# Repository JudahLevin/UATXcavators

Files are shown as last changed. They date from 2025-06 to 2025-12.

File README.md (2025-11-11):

# Purpose of this repo
Facilitate UATXcavators technical subTeam comms with a Notification System that is Automated (NSA): changes are made known to *all relevant subTeam members* with no manual effort.

# What this repo does
- Logs commits from live edits of the UATXcavators' technical Google Sheets in "logs" folder
- Acts as the primary location for making commits to UATXcavators' technical docs
- Broadcasts commits to the UATXcavators Discord to be interpreted by relevant subTeam members

---
Relevant doc/sheet links: 

## [UATXcavators Part Specs](https://docs.google.com/spreadsheets/d/1raRMg_BoY4irnRXD5xzt5HqwL2nL2Hntu02hM1NV3XU/edit?usp=sharing)
## [Industrial Automation Specs](https://docs.google.com/document/d/1iF8lcYDWoOoWy3NKHDPTQ_0LZirL0NmDES7pJT3RLTE/edit?usp=sharing)
## [How to control the prototype actuator](https://docs.google.com/document/d/1RFi-qUUx1wFrG9wh1VayHfOVhKBDCqDUs143Y6IG7fw/edit?usp=sharing)

🚨 To reiterate 🚨:
- All technical spreadsheet changes are made in linked Google Sheets.
- All technical document changes are made in this UATXcavators repo or linked Google Docs.

To join our Discord for subTeam comms and the AI summary system, [click this link.](https://discord.gg/Ns4jA3gE)

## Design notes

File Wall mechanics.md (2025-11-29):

## Stress from Torque on Segment / Push Plate / L-Bracket Bolts

**Given:**

- $$n = 4$$  
- Worst-case torque per rib: $$T = 1000\ \text{Nm}$$  
- Minimum bolt radius: $$r = 0.225\ \text{m}$$  
- Net bolt force:  
  $$F_{\text{bolt}} = \frac{T}{r} = 4444.4\ \text{N}$$

**Bolt Shear Check**

- Allowable shear for metric Grade 8:  
  $$\tau_{\text{allow}} = 0.3\,\sigma_y = 249\ \text{MPa}$$
- Required bolt shear area:  
  $$A_{\text{req}} = \frac{F_{\text{bolt}}}{\tau_{\text{allow}}} = 0.00001716\ \text{m}^2$$
- Actual tensile stress area (1/2"-28 Grade 8 hex bolt):  
  $$A = 0.0001096772\ \text{m}^2 \gg A_{\text{req}}$$

---

## Bearing on the 3/8" Plate Around the Bolt Hole

- Allowable bearing stress (SF = 4):  
  $$p_{\text{allow}} = \frac{\sigma_y}{4} = 62.5\ \text{MPa}$$
- Bolt diameter: $$d = 0.0127\ \text{m}$$  
- Plate thickness: $$t = 0.009525\ \text{m}$$  
- Bearing stress:  
  $$p = \frac{F_{\text{bolt}}}{d\,t} = 36.7\ \text{MPa} < p_{\text{allow}}$$

We do not worry about bracket rotation because four L-brackets are equally spaced around the segment and balanced for torque.

---

## Segment / Push Plate Rib L-Bracket — Axial Check

- $$n = 4$$  
- Hole diameter: $$d = 0.0127\ \text{m}$$  
- Width: $$b = 0.0381\ \text{m}$$  
- L-bracket thickness: $$t_l = 0.01905\ \text{m}$$  
- Plate thickness: $$t_p = 0.0095\ \text{m}$$  
- Applied force on upright leg: $$F = 8896\ \text{N}$$

### Section Properties

- Second moment of area:  
  $$I = \frac{b\,t_l^3}{12} = 2.2\times 10^{-8}\ \text{m}^4$$
- Neutral-axis extreme fiber:  
  $$c = \frac{b}{2} = 0.01905\ \text{m}$$
- Load height:  
  $$h_v = 0.01905\ \text{m}$$

### Allowable Deflection

- $$\delta_{\text{allow}} = \frac{h_v}{300} = 0.0000635\ \text{m}$$

### Bending Stress at the Heel

- $$\sigma_b = \frac{6Fh_v}{b\,t_l^2} = 73.5\ \text{MPa}$$  
  (within allowable, ~4× FOS)

### Shear Stress at the Heel

- $$\tau = \frac{F}{b\,t_l} = 12.3\ \text{MPa}$$  
  (well within allowable)

### Bearing Stress on Plate at Bolt Hole

- $$\sigma_{\text{bearing}} = \frac{F_{\text{bolt}}}{t_p\,d} = 73.7\ \text{MPa}$$  
  (within allowable)

### Bracket Deflection

- $$\delta = \frac{F\,h_v^3}{3EI} = 0.00000466\ \text{m}$$  
  (far below $$\delta_{\text{allow}}$$)

---

# TBM Wall Axial Stress

**Given:**

- Axial compression: $$N = 35585\ \text{N}$$
- Wall/rib length: $$L = 0.508\ \text{m}$$
- Bending moment (worst case): $$M = 18077\ \text{Nm}$$
- Allowable combined stress (4× FOS):  
  $$\sigma_{\text{allow}} = \frac{\sigma_y}{4} = 60\ \text{MPa}$$
- Rib radius: $$R = 0.27\ \text{m}$$
- Number of ribs: $$n = 4$$
- Rib area: $$A = \text{unknown (solve for required)}$$  
- Skin: 12-gauge sheet (≈2.7 mm) forming thin cylinder

### Axial Stress

Treat ribs as $$n$$ point-areas around radius $$R$$:

- Axial stress:  
  $$\sigma_N = \frac{N}{nA}$$

### Bending Stress from Wall Moment

Section inertia (ribs dominate):

- $$I = n A R^2$$

Bending stress:

- $$\sigma_b = \frac{M R}{I} = \frac{M}{n A R}$$

### Combined Stress

- $$\sigma_c = \sigma_N + \sigma_b$$
- $$\sigma_c = \frac{N}{nA} + \frac{M}{nAR} = \frac{N + \frac{M}{R}}{nA}$$

Set equal to allowable:

- $$A \ge \frac{N + M/R}{n\,\sigma_{\text{allow}}}$$

Numerically:

- $$A \ge \frac{35585 + 18077/0.27}{4 \cdot 60\times 10^6} = 0.000427\ \text{m}^2$$

This corresponds to a rib cross-section of:

- $$21\ \text{mm} \times 21\ \text{mm}$$  
meeting minimum stress requirements.

---

# TBM Wall Rib Buckling Check

- Rib load (per rib): $$P_{\text{rib}} = 8896\ \text{N}$$
- Young’s modulus: $$E = 200\ \text{GPa}$$
- Effective length factor (pinned–pinned): $$K = 1$$
- Rib height/length: $$L = 0.508\ \text{m}$$
- Rib width = $$b$$, thickness = $$t$$

### Euler Buckling Load

For a rectangular rib:

- $$P_{\text{cr}} = \frac{\pi^2 E\, t\, b^3}{12 (K L)^2}$$

With 4× FOS:

- $$P_{\text{cr}} = 35585\ \text{N}$$

Solve for minimum stiffness product:

- $$t b^3 \ge \frac{P_{\text{cr}} \cdot 12 (K L)^2}{\pi^2 E} = 5.6\times 10^{-8}$$

### Example Rib Size (Radially Oriented for Strong Axis)

Let:

- $$b = 38.1\ \text{mm} = 0.0381\ \text{m} \ \text{(1.5 in)}$$  
- $$t = 38.1\ \text{mm} = 0.0381\ \text{m} \ \text{(1.5 in)}$$

Then:

- $$t b^3 = 0.0381^4 = 2.11\times 10^{-6} \gg 5.6\times 10^{-8}$$
- Cross-section area:  
  $$b t = .00145\ \text{m}^2 \gg 0.000427\ \text{m}^2$$

**Conclusion:**  
A 38.1 mm × 38.1 mm (1.5 in × 1.5 in) rib vastly exceeds both bending-compression and Euler-buckling requirements, even under 4× safety factor.

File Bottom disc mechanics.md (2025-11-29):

# Cantilever-Strip and Stiffened-Strip Model for Ring Plate Under Column Loads

## 1. Setup and Problem Description

We have a **flat annular plate (ring)**:

* Inner diameter (ID) is **fixed** (built-in support).
* Outer diameter (OD) is **free**, except at **four square columns** welded/bolted along the outer edge.
* Each column is loaded in **downward axial force** (in side view), so the plate is loaded in **out-of-plane bending**.
* The ID reacts these loads by providing a fixed (clamped) support around the inner circumference.

Rather than analyzing the entire ring at once, we look at **one representative strip** of plate **under a column**, and model how that strip bends out of plane between:

* The **ID clamp** (fixed end), and
* The **column footprint at the OD** (loaded end).

The goal is:

1. Show that a **bare plate** is overstressed under the column load.
2. Develop a **composite plate + stiffener model** to reduce bending stress to acceptable levels.

---

## 2. Justification for the Cantilever-Strip Model

Because:

* The column load is localized under each column footprint, and
* The ID is effectively a continuous fixed support,

it is reasonable to idealize:

* A **radial strip** of the plate, of effective width $$b$$, under a given column.
* That strip behaves approximately like a **cantilever beam**:

  * Fixed at the ID (built-in),
  * Span length $$L$$ (radial distance from ID to column),
  * Tip load $$F$$ (column load per strip).

This ignores 2D plate effects and circumferential load spreading, but it is **conservative** for checking local bending under a column because:

* Bending is highest near the fixed end.
* The strip model directly captures the dominant bending mechanism: **radial plate bending between OD and ID**.

So we treat the plate strip as a **rectangular-section cantilever beam** with:

* Beam depth (bending direction): plate thickness $$t$$
* Beam width (into page): effective width $$b$$

---

## 3. Un-Stiffened Plate: Bending Stress Check

For a **bare plate strip** (no rib):

* Cantilever span:
  $$L = 0.17911976\ \text{m}$$
* Plate thickness:
  $$t = 0.0127\ \text{m}$$
* Effective strip width:
  $$b = 0.05\ \text{m}$$
* Tip load (per strip):
  $$F = 8896.4\ \text{N}$$

### 3.1. Bending moment at the fixed end

For a tip-loaded cantilever:

$$
M_{\max} = F L
= 8896.4 \cdot 0.17911976
\approx 1593.5\ \text{N·m}
$$

### 3.2. Section properties of the plate strip

Rectangular cross-section (width $$b$$, thickness $$t$$):

* Second moment of area:

$$
I = \frac{b t^3}{12}
\approx 8.53 \times 10^{-9}\ \text{m}^4
$$

* Distance to extreme fiber (top/bottom):

$$
c = \frac{t}{2} = 0.00635\ \text{m}
$$

### 3.3. Maximum bending stress

$$
\sigma_{\max}
= \frac{M_{\max} c}{I}
= \frac{1593.5 \cdot 0.00635}{8.53 \times 10^{-9}}
\approx 1.19 \times 10^{9}\ \text{Pa}
= 1186\ \text{MPa}
$$

This is **far above** the yield strength of typical structural steels (e.g. 250–500 MPa).
Conclusion: **a 12.7 mm plate alone is nowhere near sufficient** for this load and span, and requires stiffening.

---

## 4. Composite Plate + Stiffener Model (New Coordinate System)

To reduce bending stress, we weld a **longitudinal stiffening rib** under the plate strip, along the entire span. The plate + stiffener form a **T-shaped composite section**.

We use the following **right-hand 3D coordinate system**:

* **Y**: vertical **height** direction (bending direction)
* **Z**: along the **cantilever length** (span), from fixed end to loaded end
* **X**: through-plate **thickness** direction

We analyze the T-section in the **Y–Z plane**, with bending about the **X-axis**.

### 4.1. Geometry and variables

* Plate (flange):

  * Thickness in X:
    $$t\ (\text{m})$$
  * Effective strip width (circumferential):
    $$b\ (\text{m})$$

* Stiffener (web):

  * Height in Y (from plate underside down):
    $$h\ (\text{m})$$
  * Thickness in X:
    $$t_s\ (\text{m})$$

* Cantilever span in Z:
  $$L\ (\text{m})$$

* Tip load at $$Z = L$$:
  $$F\ (\text{N})$$

### 4.2. Coordinate convention in Y

Let:

* $$Y = 0$$: **bottom of the stiffener**
* $$Y = h$$: **plate–stiffener interface**
* $$Y = h + t$$: **top of the plate**

### 4.3. Component areas

$$
A_p = b t
$$

$$
A_s = h t_s
$$

$$
A = A_p + A_s
$$

### 4.4. Component centroids (in Y)

$$
Y_p = h + \frac{t}{2}
$$

$$
Y_s = \frac{h}{2}
$$

### 4.5. Neutral axis location $$\bar{Y}$$ (from bottom of stiffener)

$$
\bar{Y}
= \frac{A_p Y_p + A_s Y_s}{A_p + A_s}
= \frac{b t \left(h + \frac{t}{2}\right) + h t_s \left(\frac{h}{2}\right)}
{b t + h t_s}
$$

### 4.6. Second moment of area about the neutral axis

Plate local inertia:

$$
I_{p0} = \frac{b t^3}{12}
$$

Shifted:

$$
I_p = I_{p0} + A_p (Y_p - \bar{Y})^2
$$

Stiffener local inertia:

$$
I_{s0} = \frac{t_s h^3}{12}
$$

Shifted:

$$
I_s = I_{s0} + A_s (\bar{Y} - Y_s)^2
$$

Total:

$$
I = I_p + I_s
$$

### 4.7. Extreme fiber distances

Top:

$$
Y_{\text{top}} = h + t
$$

$$
c_{\text{top}} = (h + t) - \bar{Y}
$$

Bottom:

$$
c_{\text{bot}} = \bar{Y}
$$

Largest:

$$
c_{\max} = \max(c_{\text{top}},\ c_{\text{bot}})
$$

### 4.8. Bending moment and maximum stress

$$
M_{\max} = F L
$$

Stress at distance $$c$$:

$$
\sigma = \frac{M_{\max} c}{I}
$$

Maximum:

$$
\sigma_{\max}
= \frac{F L , c_{\max}}{I}
= \frac{F L , \max\left((h + t) - \bar{Y},\ \bar{Y}\right)}
{I_p + I_s}
$$

with:

$$
I_p = \frac{b t^3}{12} + b t (Y_p - \bar{Y})^2
$$

$$
I_s = \frac{t_s h^3}{12} + h t_s (\bar{Y} - Y_s)^2
$$

and:

$$
Y_p = h + \frac{t}{2}, \quad
Y_s = \frac{h}{2}, \quad
\bar{Y}
= \frac{b t \left(h + \frac{t}{2}\right) + h t_s \left(\frac{h}{2}\right)}
{b t + h t_s}
$$

This model gives us a **closed-form way to size the stiffener** ($$h, t_s$$) and effective strip width $$b$$ for a given load $$F$$, span $$L$$, and plate thickness $$t$$ to ensure:

$$
\sigma_{\max} \leq \sigma_{\text{allowable}}
$$

for the chosen material and safety factor.

---

## 5. Numerical Example: Stiffened-Strip Bending Stress Calculation

This section applies the composite stiffened-strip model to a representative geometry. A plate strip of width $$b$$ is reinforced by a vertical stiffener of height $$h$$ and thickness $$t_s$$, forming a T-shaped composite section. The strip behaves as a cantilever of span $$L$$ carrying a tip load $$F$$.

### 5.1. Input Geometry and Loading

* Plate thickness:
  $$t = 0.009525\ \text{m}$$
* Plate strip width:
  $$b = 0.05\ \text{m}$$
* Stiffener height:
  $$h = 0.075\ \text{m}$$
* Stiffener thickness:
  $$t_s = 0.025\ \text{m}$$
* Tip load:
  $$F = 8896.4\ \text{N}$$
* Cantilever span:
  $$L = 0.17911976\ \text{m}$$

The coordinate system uses:

* $$Y$$: vertical direction (plate + stiffener height)
* $$Z$$: cantilever length
* $$X$$: plate/stiffener thickness direction

---

### 5.2. Cross-Sectional Properties

Plate area:

$$
A_p = b t = 4.7625\times 10^{-4}\ \text{m}^2
$$

Stiffener area:

$$
A_s = t_s h = 1.875\times 10^{-3}\ \text{m}^2
$$

Plate centroid:

$$
Y_p = h + \frac{t}{2} = 0.0797625\ \text{m}
$$

Stiffener centroid:

$$
Y_s = \frac{h}{2} = 0.0375\ \text{m}
$$

Composite neutral axis (from bottom of stiffener):

$$
\bar{Y}
= \frac{A_p Y_p + A_s Y_s}{A_p + A_s}
\approx 0.0461\ \text{m}
$$

---

### 5.3. Second Moment of Area

Plate about its own centroid:

$$
I_{p0} = \frac{b t^3}{12} \approx 3.60\times 10^{-9}\ \text{m}^4
$$

Shifted to global NA:

$$
I_p = I_{p0} + A_p (Y_p - \bar{Y})^2
\approx 5.45\times 10^{-7}\ \text{m}^4
$$

Stiffener about its own centroid:

$$
I_{s0} = \frac{t_s h^3}{12} \approx 8.79\times 10^{-7}\ \text{m}^4
$$

Shifted to global NA:

$$
I_s = I_{s0} + A_s (\bar{Y} - Y_s)^2
\approx 1.02\times 10^{-6}\ \text{m}^4
$$

Total composite inertia:

$$
I = I_p + I_s \approx 1.56\times 10^{-6}\ \text{m}^4
$$

---

### 5.4. Extreme-Fiber Distances

Top of plate at $$Y = h + t = 0.084525\ \text{m}$$:

$$
c_{\text{top}} = (h+t) - \bar{Y} \approx 0.0385\ \text{m}
$$

Bottom of stiffener at $$Y = 0$$:

$$
c_{\text{bot}} = \bar{Y} \approx 0.0461\ \text{m}
$$

Maximum distance:

$$
c_{\max} = c_{\text{bot}}
$$

---

### 5.5. Bending Moment and Stress

Maximum bending moment at the fixed end:

$$
M_{\max} = F L
= 8896.4 \cdot 0.17911976
\approx 1593.5\ \text{N·m}
$$

Top fiber stress:

$$
\sigma_{\text{top}} = \frac{M_{\max} c_{\text{top}}}{I}
\approx 3.93 \times 10^{7}\ \text{Pa}
= 39.3\ \text{MPa}
$$

Bottom fiber stress:

$$
\sigma_{\text{bot}} = \frac{M_{\max} c_{\text{bot}}}{I}
\approx 4.70 \times 10^{7}\ \text{Pa}
= 47.0\ \text{MPa}
$$

Maximum bending stress:

$$
\boxed{\sigma_{\max} \approx 47\ \text{MPa}}
$$

---

### 5.6. Interpretation

Even with a relatively thin plate ($$t=9.5\ \text{mm}$$), the stiffener of height $$h=75\ \text{mm}$$ and thickness $$t_s=25\ \text{mm}$$ dramatically increases the bending rigidity. Under the applied load of $$F=8896.4\ \text{N}$$ at a span of $$L=0.17911976\ \text{m}$$, the resulting bending stress is:

* $$\sigma_{\max} \approx 47\ \text{MPa}$$, giving
* $$\text{SF} \approx \dfrac{250}{47} \approx 5.3$$ against $$250\ \text{MPa}$$ steel, or
* $$\text{SF} \approx \dfrac{350}{47} \approx 7.5$$ against $$350\ \text{MPa}$$ steel.

This confirms the stiffened-strip approach provides a structurally sound load path for the ring plate under column loads for the updated shorter cantilever span.

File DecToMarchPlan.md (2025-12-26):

# UATXcavators Plans December - March

The problem: we need to build a functional tunnel boring machine by the end of March 2026.

## Needs
* Compute mechanical **load justifications** for TBM design
* Complete **CAD**
* Design detailed electrical **schematics**
* Purchase **electrical equipment** (e.g. breakers, contactors)
* Purchase the **cutterhead motor and gearbox**
* Purchase the **screw jack**
* Set up **hydrovac truck rental** for competition week
* Purchase **steel**
* **Fabricate** our in-house steel parts

## Order of operations Dec 21 - Jan 5
1. JUDAH - MECHANICAL: Source and buy the motor/gearbox and screw jack because of lead time 
    1. ✅ Complete and justify TBM diameter + cutterhead design for torque/RPM and thrust/stroke length computation
    2. ✅ Refine the technical spec mathematical results with literature
    3. Justify torque/RPM and thrust specs of each w/ Cole (for solidifying the design and avoiding expensive mistakes)
    4. Select a compatible VFD for the cutterhead motor
    5. Motor/gearbox note: search motor by horsepower, gearbox by output torque and reduction, both by NEMA/IEC size
    6. Find multiple product options for each online, diversify across different Austin distributors (for lead time and purchase failure margin of safety)
    7. Call the distributors and pay for fastest delivery (time is more important than money)
*12-16 update: we are pivoting to simply buy from either NORD or our original SEW friends (whoever responds faster)*
2. EITAN - ELECTRICAL: Design and purchase the electrical system/parts 
    1. ✅ Make a readable and clear diagram that interconnects all our power sources, actuators, sensors, and controls. We want to visualize the setup so we can detect missing parts. 
    2. Present the diagram to Cole and work with him to finalize it. 
    3. Once diagram is finalized, write up a complete BOM of cables, electronics, power equipment, sensors, and controls parts we need. Optimize for delivery speed.
    4. *12-16 update: make a state diagram of the entire machine operation with variable names and unit values for our programming/comms person*
    5. Purchase everything electrical on the BOM.
    6. Determine LOTO and safety equipment required and add to the BOM.
    7. Purchase everything for safety on the BOM.
3. JUDAH - MECHANICAL:
    1. Compute load rating ranges and run FEA analysis on TBM and launch frame structure based on our sourced cutterhead gearmotor and screw jack dimensions and forces.
    2. Get steel, bolt, and D-ring dimensions and design for both operation and mounting/transportation. Then, justify w/ Cole.
    3. Implement all designs and dimensions in fully assembled TBM CAD. This is our optimal design which acts as the basis for the TBM we actually build, given raw material supply and machining limitations.
    4. Visit local machine and steel shops (so we can get fast delivery/feedback cycles) and meet with experts to change the design given practical manufacturing factors: *record* steel size availability, equipment cost/access, and machining costs/time. Make tolerance compromises and structural substitutions (which are close to the optimal CAD).
    5. Write a BOM including all steel and bolt parts and machining needs.
    6. Purchase the BOM.
    8. Source equipment, location options required for assembly, as well as possible storage and transportation methods (e.g. call local towing companies).
    9. Write up fabrication, assembly, and logistic plans and timelines for execution during school time.

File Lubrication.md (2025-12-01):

Bearing model: [TIMKEN 23140-EMB-W33](https://cad.timken.com/item/spherical-roller-bearings/spherical-roller-bearings-brass-cage/23140embw33)

Grease model: [Timken Construction and Off-Highway Grease](https://www.timken.com/products/timken-mechanical-power-transmission-products/lubrication-lubrication-systems/construction-and-off-highway-grease/)

Grease properties:
* Heavy Loads
* High Sliding Wear
* Dirty Environments
* Slow Speeds
* Shock Loading
* [1022gm grease qt. for 90% fill / 1261.7cm^3 bearing free volume = 810kg/m^3 grease density](https://engineering.timken.com/engineering-tool/grease-lubrication-tool/)
* [~200cSt at operating temp 60C](https://engineering.timken.com/engineering-tool/grease-lubrication-tool/)
* ~40cSt at worst-case temp 90C

$$\text{Dynamic Viscosity (Pa·s)} = [\text{Kinematic Viscosity (m/s)}] \times [\text{Density (kg/m}^3)]$$
  
$$\mu\(\text{Pa}\cdot\text{s}) = \nu\(\text{cSt}) \times \rho\(\text{kg/m}^3) \times 10^{-6}$$

=> normal case $\mu$ = 0.162Pa·s and worst-case $\mu$ = 0.0324Pa·s

Each relubrication requires 102.8g of grease. At operating temp 60C, relube every 11171hrs and at worst-case 90C, relube every 2793 hours. Given our negligible operating timespan, we do not need to relube again after the initial greasing of 1022g (see above).

A labyrinth seal is our best option to stop dirt ingress because it does not require contact with the shaft and can be more cheaply and easily fabricated in-house. For highly viscous fluids like muck, Poiseuille's Law dominates (as opposed to Bernoulli's principle of inviscid fluids). This means that muck is slowed down by the friction of the narrow axial gap between spinning teeth and the stationary, flat plate.

Then, given the ID/OD of the labyrinth equals the 200mm ID and 340mm OD, the effective radius $r_{\text{eff}}$ = 135mm. Then, $b$, the circumferential width of the flow path, is $2\pi r$ = 848mm. 

Given our bearing model's 2.5-degree misalignment tolerance from the vertical we can determine $g$, the gap height of the labyrinth seal, by computing the axial depression of the T-shaped rotor with radius $r = .07m$ after misalignment:

$$g = r\sin(\theta) = 0.0031m$$.

Our grease pump model: [SK-505 Lubricator](https://www.amazon.com/ZHHWKNBD-Electric-Automatic-Lubricating-SK505BM-1/dp/B0F26YD4YX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): 

Grease pump properties:
* [13 cc/min @ no load / negligible resistance](https://lubeng.com.au/wp-content/uploads/2019/10/SLP-SK-505-Grease-pump_DS-R4.pdf?utm_source=chatgpt.com
)

* ~6 cc/min @ full-load / maximum rated resistance

$$Q = vbg$$

Where:

- $Q$ = volumetric flow rate of grease (m³/s)
- $v$ = average outward grease velocity (m/s)

So, at maximum rated resistance 1e-7m³/s, $g = 0.0031m$, and b = .848m (see above) we can expect $v = Q/(bg)$ = 0.0000386m/s, or around 3.9mm/s.

Now, we can check our laminar flow assumption:

$$\text{Re} = \frac{\rho vg}{\mu}$$

- $$\text{Re}$$ — Reynolds number  
- $$\rho$$ — fluid density

Given our numbers above, including $\rho$ = 810kg/m^3, $\text{Re}$ =0.0029 << 1. This confirms that the viscous forces in the labyrinth's fluid flow are significantly dominant over the inertial forces.

$$\Delta P = \frac{12\mu vL}{g^2}$$

Where:
- $L$ = effective restriction length (m)

According to our worst-case numbers, $\frac{\Delta P}{L} = 1.6Pa/m$. Since $L$ has an upper bound of $r$ (see above), that gets 0.113Pa max with our current $g$. Here, viscous resistance is negligible and the muck will not slow down. Since $g^2$ is dominant in this equation, it is clear $g$ must be decreased.

Suppose instead of using the same axial gap for all teeth, we use stepped teeth that start at a small axial gap and increase toward 6.9mm max.

At some radius $r$ along the rotor, s.t. $r \in \[0, .07\]$ m, we can compute the $g$ required as:

$$r \sin(2.5 \text{ degrees})$$

Now, we can compute the largest allowable $g$ given $\Delta P$, by computing the radial pressure difference between the muck region and the bearing / labyrinth region:

$$\Delta P \approx \frac{1}{2}\rho \omega^2 (r_o^2 - r_i^2)$$

So, we can get a conservative $g$ by finding the minimum $r_i$, which is the ID/2 of the bearing, and the maximum $r_o$, the ID/2 of the muck reservoir. Then, at 0.524rad/s (5RPM), and 1600kg/m^3 density of muck, we get 94.2Pa. 
We also add hydrostatic pressure, given that the muck reservoir is completely filled and the labyrinth is 135mm from the muck reservoir top, to get $P_\text{hydrostatic} = \rho \g \h$ = 2112Pa. 

Now, we add the total radial and hydrostatic pressure to get 2213Pa. Since we want local grease pressure at the labyrinth gap slightly higher than the local muck pressure, multiply by 2x FOS to get 4.4kPa. Thus, plugging in the values to the $\Delta P$ equation we get 4.51mm.

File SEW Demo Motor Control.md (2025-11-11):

# SEW Demo Motor Control

## 🟢 Startup Procedure

1. Plug in transformer  
2. Switch transformer **ON**  
3. Turn **motor key switch to “O”**  
4. Rotate **black lever vertically**  
5. On the HMI screen, press **Start → OK**  
6. Plug in **mini USB**

---

## ⚙️ Communication Setup

1. Navigate to: **Settings → Communication → Scan + Apply**  
2. Press **Scan** (top right)  

---

## ▶️ To Turn On

1. Open **MOVIKIT Diagnostics → Activate**
2. Set the following values:

| Parameter | Value |
|---|---|
| Enable / Emergency Stop | 1 |
| Enable / Application Stop | 1 |
| Activate Output Stage Inhibit | 0 |
| Start / Stop with Fields Ramp | 1 |
| Setpoint Speed | `[desired speed]` |

---

## ⏹ To Turn Off

Do everything **in reverse order** of the startup sequence.

---

## 📈 Viewing Scope Data (e.g., Torque)

1. Hit **Back**  
2. Select **Yes** to deactivate  
3. Open **Right Project → Tools → Scope**  
4. Click the **red “SCOPE”** button → *Recording Channel*  
5. Double-click **Lag Error**  
6. Enter value **8364.95** and press **Apply**  
   - You may toggle off any functions you don’t want to display  
7. Click **red SCOPE → Trigger → 9: Status Bits**  
8. Turn **Bit 1: Output Stage Enabled → 1s** and **Apply**  
9. Go to **Controls → Apply**

---

## 🧪 Creating a New Measurement

1. In the **Live Data** window, right-click the **Measurements** folder on the left.  
2. Select **Create New Measurement**.  
3. Verify the measurement pop-up shows the same scope values, then click **Apply**.

---

## 🧩 Recording Data

1. Go to the **Home Page** (with the two bubbles icon).  
2. Right-click on the **red control box**.  
3. Select **Activate Manual Mode**.  
4. In the **Live Data** window:
   - Press the **Play ▶️** button (top right).  
   - Set a **velocity** in the manual controls area.  
   - Turn **ON** the motor.  
5. The central graph should now populate with **live input data** from the motor.

---

✅ **Tip:** Save your scope or measurement configuration files after successful tests so you can reload them instantly for future demos.

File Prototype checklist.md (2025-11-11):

# Setup

### Linear actuator
* Red jumper goes to ENA and +24VDC
* Black and red wires go to GND and +24VDC
* Use a 240VAC receptacle for voltage stability
* Place the controller close to the launch structure so the wires of the controller and driver can reach the PSU

### Motor & Driver
* B- -> Blue
* B+ -> Red
* A- -> Green
* A+ -> Black
* PUL- -> IO18
* DIR- -> IO19
* ENA- -> IO21
* GND -> - rail
* Vin -> +rail
* PUL+ -> +rail
* DIR+ -> +rail
* ENA+ -> +rail
* Use green USB->micro from the ESP32 to operator
* Situate the operator close to the launch structure

For adding current/torque sensors:
* OUT1 or OUT2 -> IO34
* Vin/GND power
* Outputs in-line with one of the driver-to-motor wires

PSU:
* Black from controller and driver on -
* Red from controller and driver on +

Vac:
* Pointy side of tube goes into the bucket's button side

Generator:
* Gentle surges after some oepration time is okay
* Turn on before plugging stuff in (reset circuit breakers as needed)

# Operation Checklist

* Use a continuous stroke rate on the linear actuator
* Pulse the vacuum to clear silty muck, then turn off the vacuum and spray conditioner. This makes it more watery.
* During stalls, jog the linear actuator up OR reverse direction on the motor. If jogging up, pause and let the cutter head turn for a few seconds before resuming continuous extension.

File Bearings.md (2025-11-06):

# Bearings

[Timken Thrust Bearing Catalog](https://catalog.timken.com/Thrust-Bearing-Catalog/18/)

* *Cageless* allows for more load capacity at lower speed since the densely packed rollers increase friction
* *Tapered bearings* are best suited to withstand the shocks or vibrations that will cause radial misalignment. We expect some radial load due to cutting imbalances and moments, as well as ground resistance.
* *Double-acting bearings* handle bidirectional loads for extending the linear actuator and retracting it while carrying the TBM weight.
* Type TTD bearings are double-acting thrust tapered roller bearings
* Angular contact bearings are better suited to radial loads than thrust spherical roller bearings (e.g., tapered, barrel ones) because they don't slide off the raceway but are held in place by angled, flat faces. To calculate the Dynamic Equivalent Thrust Load ($P_a$), the multiplier for radial load ($F_r$) is 1.2 for dynamic spherical (2.7 for static) and .76 for angular contact (p. 20), indicating that the spherical type is more sensitive to radial, dynamically and statically. Also, the axial load ($F_a$) is equally sensitive in both cases. 
* $P_a$ determines the life of the bearing
* Clay is soft and ductile, which can cause lubrication and sealing problems, though fewer mechanical issues.
* Rock is hard and brittle, which is more damaging than clay, particularly mechanically, as it can be both ductile and brittle.
* Significantly more misalignment tolerance in thrust ball bearings than any other type
* DTVL is bidirectional angular contact (mounting on p. 36)
* Worst case speed: 30 RPM or 3.14 rad/s. The heat generation and energy loss due to the bearing are a result of the operation speed, thrust load, lubrication viscosity, and bearing geometry/torque factors.
* *Grease* can act as a sealant, not oil, which is necessary for blocking muck, and better for low-speed applications. Aluminum and Calcium sulfonate greases have the most excellent resistance to water ingress. We want to choose a grease that will resist abrasive particles and water to reduce wear. Timken Construction and Off-Highway Grease, for instance, is meant for dirty environments (p. 60).
* Only for low-speed applications can the entire housing be filled with grease to protect against moisture and contaminants.
* The smallest angular contact TVL has 11.6 in OD, thrust cylindrical roller 6 in, tapered roller has 4 in ID, but the DTBL (double-acting) is too wide.

# Couplers

* Our motor is a 3.625" diameter bore with a 7/8" key
* Increasing the diameter and decreasing the length of the support decreases the bending normal and torsional shear of a shaft at a cubic rate.
* Longer, thicker, taller keys decrease bearing stress.
* Unbalance, vibration forces from the cutter head increase at the square of the RPM. This vibration can dominate if the RPM is too high. But at 5 RPM, there is very little vibrational imbalance, and heat in the elastomer is minimal.
* More OD in rubber increases torque capacity. Increasing axial height absorbs greater forces due to the higher material volume, as well as increases misalignment capacity because angular deflections are stretched out over a longer length. Hardness is measured by a durometer, allowing for increased torque capacity but less shock absorption (more brittle). The durometer grades in increasing hardness are 64A, 80A, 92A, and 98A.
* A flexible coupler acts as a spring or damper to protect the gearbox output against shock loads and misalignment.
* The coupler must handle peak torque, e.g., when hitting a rock, at 3x nominal torque => 12,000 Nm.
* The softer the material, the less torque transmitted since some force is absorbed as it compresses. But it allows for better shock absorption and misalignment protection.
* We will buy a few hardness levels of spider elastomers and fabricate the hub.
* H-type is capacious enough. [ROTEX sizes 110 and up have sufficient torque, in particular](https://www.ktr.com/fileadmin/ktr/media/Tools_Downloads/kataloge/01_flexible_jaw_bin_bush_ROTEX.pdf) That size corresponds with about 200mm diameter, 300mm length.
* We are optimizing to minimize backlash and OD for compactness and more open space on the cutter head.
* [Here is the CAD library](https://www.ktr.com/us/en/services-and-tools/cad-library/3d-cad-library/): ROTEX -> 001 (standard) -> 125/110

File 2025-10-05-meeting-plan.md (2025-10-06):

Here is the current roster, including the subTeam "heads":

### Electrical/Software (ES) subTeam:
- Nico Kokonas  
- Nathan Prundeanu  
- Noah Prundeanu  
- Earl Hoffmann  
- Eitan Zarin - Electrical, and Max Weinstein - Software; (Heads)  

### Mechanical/Mucking/Conditioning (MMC) subTeam:
- Harland Carmine  
- Pierce Crist  
- Samuel McClure  
- Jack Porter  
- Hunter Lin
- JR Crawford
- Thomas Olson  
- Sam Indyk - Conditioning; and Judah Levin - Mechanical/Mucking; (Heads)  

---

Max reviews our Notification System that is Automated (NSA). Everyone understands how and when to use it. Everyone joins GitHub and Discord.  
Judah presents October Tests and Ground Rules, NABC rules pp. 9-13, pp. 26-28, Final Design Package - Digging Mini Competition, Mining Readiness Review, and Competition Safety Inspections (pp. 39-44). Judah gauges interest in D-term work near The Boring Company facility.

---

### Conditioning
- Read all relevant NABC rules:  
  - Sec 6 (pp. 18-19)  
- Plan Conditioning Test  
- Make a BOM (include logistical expenses) for test 1 so we can order now, and so the electrical team can plan cabling  
- White-box the items for test 1.  
- Determine the specs/design of and where to source the following. Prove each one with supporting calculations:  
  - Ultrasound emitters  
  - Spray nozzles  
  - Muck transport system: auger vs. conveyor vs. pump.  
- **By Monday, October 13th:** make a state diagram  

---

### Electrical
- Read all relevant NABC rules:  
  - Sec 7 (pp. 19-21)  
- Determine electrical low and high alarms for the IO list  
- Collaborate with the MMC subTeam to plan wiring and cabling for the Conditioning Test and Forces Test. Append electrical parts to their respective BOMs.  

---

### Software
- Read all relevant NABC rules:  
  - Sec 8, 9, 10 (pp. 21-25)  
- Code up controls logic for test 1 using an FPGA and a GUI to control a solenoid valve and pump  
- **By Monday, October 13th:** write an NABC-compliant IO list with Electrical’s & MMC’s alarm values  

---

### Mechanical & Mucking
- Read all relevant NABC rules:  
  - pp. 14  
- Plan Cutter Head Test and Forces Test, and put together a BOM.  
- Review muck disposal with Jack.  
- Determine hydraulics vs electric. Determine multiple motors vs one motor.  
- Determine where to place sensors  
- Review simulations and designs based on TBC, AECOM, and Alex’s advice  
- Record low and high alarm values for all mechanical sensor values.  
- Source a screw jack and a jack motor  
- Source metal and fab shops

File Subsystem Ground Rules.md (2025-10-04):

# Subsystem Ground Rules

---

## 1. White-Box Your Part

To test or fix a part you bought off-the-shelf, you need to understand how it works — it cannot be a black box.  
For each piece of hardware (e.g., a pump), understand the following:

### 1. Basic Identification
- **Type:** Centrifugal, diaphragm, peristaltic, screw, gear, etc. (each has different response curves and failure modes).  
- **Intended service:** Water, slurry, foam solution, polymer, air–liquid mix, etc.  
- **Datasheet/manual:** Gather official specs, wiring diagrams, I/O, service instructions.  

### 2. Performance Characteristics
- Flow vs. pressure curve (pump curve): how flowrate changes with discharge pressure.  
- Operating range: min/max flow, min/max pressure.  
- Efficiency curve: optimal point of operation.  
- NPSH (Net Positive Suction Head): suction requirements to avoid cavitation.  
- Priming requirements: self-priming or external priming needed.  

### 3. Mechanical & Electrical Limits
- Max RPM / duty cycle (continuous vs intermittent).  
- Power input: voltage, phase, current draw.  
- Start-up current (inrush).  
- Temperature limits: fluid and ambient.  
- Seal/shaft design: dry-run tolerance, lubrication requirements.  
- Noise/vibration levels.  

### 4. Control & Interfaces
- How it starts/stops: relay, contactor, VFD, or onboard driver.  
- Speed control: fixed-speed or variable-speed input (analog 4–20 mA, PWM, Modbus, etc.).  
- Built-in protections: thermal cutoff, overload protection.  
- Feedback signals: flow sensor, tachometer, current feedback, or none.  
- Fail-safe state: what happens if power is lost (coast, lock, vent).  

### 5. Safety & Failure Modes
- Failure points: cavitation, dry running, overheating, overpressure, seal leakage.  
- What happens if blocked: stalls, trips, or bypasses.  
- Overpressure protection: relief valve built in or external required.  
- Safe shutdown procedure: gradual vs immediate stop.  
- Hazards: shock hazard, fluid leakage, stored pressure.  

### 6. Integration Considerations
- Startup sequencing: does it need priming before flow?  
- Shutdown sequencing: does it need flush/clean cycle?  
- Maintenance cycle: lubrication, seal replacement, cleaning frequency.  
- Environmental considerations: can it run outdoors, underground, submerged?  
- Compatibility: chemical resistance of wetted parts.  

### 7. Testing Preparation
Before your test, you should know:  
- Expected flow/pressure at test conditions (compare against the curve).  
- Power draw under load (to size sensors and PSU).  
- Safe limits to enforce in the Finite State Machine (FSM).  
- Baseline sensor readings at known settings for calibration.  

### 8. Documentation to Have in Hand
- Manufacturer’s datasheet (performance curves).  
- Wiring diagram (for safe connection).  
- Operation & maintenance manual (O&M).  
- Spare parts list (seals, impellers, bearings).  
- Certifications (CE, ATEX, NSF, etc. if required).  

---

## 2. Subsystem State Diagrams

From the NABC rules, here’s a step-by-step process to build a pump state diagram inside a conditioning subsystem:

1. **Set scope & interfaces**  
   Decide what’s “the pump” vs. “the conditioning system,” and list external signals it depends on (e.g., `Safety_OK`, `Flush_Cmd`).

2. **List pump states**  
   Choose modes like `OFF`, `INIT`, `PRIMING`, `RUNNING`, `FLUSH`, `HOLD`, `FAULT`, `E_STOP`.

3. **Define entry / during / exit for each state**  
   - **Entry action:** one-time when entering (e.g., open prime valve).  
   - **During action:** continuous while in state (e.g., regulate flow).  
   - **Exit action:** one-time before leaving (e.g., close valve).  

4. **Identify transitions**  
   Write rules that change states (start/stop command, sensor condition, timer expiry).  

5. **Add permissives and interlocks**  
   Example: Permit_Pump = Safety_OK ∧ Tank_Level_OK ∧ No_Fault

6. **Tie transitions to real I/O tags**  
Example: `PT_Header` (pressure), `FM_Water` (flow), `LS_Tank_LL` (level switch).  

7. **Add timers & debounce**  
Define minimum on/off times, priming timeout, ramp-up/ramp-down.  

8. **Define setpoints & regulation in RUNNING**  
Choose flow/pressure targets and control method (fixed speed, PID, etc.).  

9. **Enumerate faults and safe reactions**  
Examples: Overpressure, no-flow/dry-run, overcurrent, bad sensor.  
Define detection, shutdown, and reset rules (latched or auto-reset).  

10. **Define fail-safe states**  
 Decide outputs if control is lost (e.g., pump OFF, valves CLOSED).  

11. **Wire pump ↔ subsystem interactions**  
 Example: subsystem `DOSE_STEADY` → pump must be `RUNNING`; subsystem `FLUSH` → pump must be `FLUSH`.  

12. **Draw the diagram (FSM)**  
 - **Boxes = states**  
 - **Arrows = transitions labeled with conditions**  

13. **Create companion tables**  
 - **State table:** State | Entry | During | Exit | Exit conditions  
 - **Permissive matrix**  
 - **Fault matrix**  

14. **Validate with test paths**  
 Walk the “happy path” (`OFF → INIT → PRIMING → RUNNING → FLUSH → OFF`) and fault paths (`RUNNING → FAULT`).  
 First simulate I/O, then run on hardware.  

---

## Example State Diagram

```mermaid
stateDiagram-v2
%% =========================
%% Top-Level: Conditioning
%% =========================
[*] --> C_OFF

C_OFF --> C_INIT: Power_On & Safety_OK
C_INIT --> C_READY: Sensors_OK & Levels_OK & Mixer_OK
C_READY --> C_DOSE: Start_Dosing & Permits_OK
C_DOSE --> C_FLUSH: Flush_Cmd | Bin_High | Stop_Dosing
C_READY --> C_FLUSH: Flush_Cmd
C_FLUSH --> C_READY: Lines_Clear & Timer_Done
C_ANY: C_OFF
C_ANY --> C_FAULT: OverP | DryRun | Sensor_Bad | Level_CritLow
C_ANY --> C_ESTOP: EStop

C_FAULT --> C_READY: Fault_Reset & Health_OK & Permits_OK
C_ESTOP --> C_OFF: Safety_Reset

state "Conditioning: DOSE_STEADY" as C_DOSE {
 [*] --> RUN_LOGIC
 RUN_LOGIC: Set flows to recipe (FIR)\nRegulate header pressure\nMonitor quality & limits
 RUN_LOGIC --> [*]: Stop_Dosing | Flush_Cmd
}

%% Notes showing interlocks between layers
note right of C_DOSE
 Requires Pump.RUNNING
 Permit_Dose = Safety_OK ∧ Tank_Level_OK ∧ No_Leak
end note

%% =========================
%% Nested: Pump FSM
%% =========================
state "Pump Subsystem" as PUMP {
 [*] --> P_OFF
 P_OFF --> P_INIT: Power_On & Safety_OK
 P_INIT --> P_PRIME: Start_Cmd & Suction_OK
 P_PRIME --> P_RUN: Flow_Detected within T_prime
 P_PRIME --> P_FAULT: Prime_Timeout | DryRun
 P_RUN --> P_FLUSH: Flush_Cmd | Stop_Cmd
 P_RUN --> P_FAULT: OverP | NoFlow | OverCurrent | Sensor_Bad
 P_FLUSH --> P_OFF: Flush_Done & Lines_Clear
 P_FAULT --> P_INIT: Fault_Reset & Health_OK
 P_ANY: P_OFF
 P_ANY --> P_ESTOP: EStop
 P_ESTOP --> P_OFF: Safety_Reset
}

%% Coupling rules (top-level → pump)
C_DOSE --> P_RUN: (Ensure) Pump.RUNNING
C_FLUSH --> P_FLUSH: Flush_Cmd
C_READY --> P_OFF: Idle

%% Global ANY aliases for readability
state C_ANY <<choice>>
state P_ANY <<choice>>

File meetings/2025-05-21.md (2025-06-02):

# 📝 UATX TBM Meeting – May 21, 2025

## Attendees
- Judah Levin
- Eitan, Kellen, Christian, Max, Sam

## Design Notes

### Cutter Head Excavation and Muck Removal System

- In the **center of the cutter head**, an **auger** is installed.
  - The auger lies within a **secondary tubing** system.
  - This tubing allows **mud and fine particles to fall through** while trapping **larger rocks**.

- Around the cutter head, within the TBM shell, there's a **domed collection chamber**:
  - Acts as a **filter**: only **mud and smaller particles** pass through.
  - **Larger rocks** remain outside the filter region.

- The **domed chamber**:
  - **Slopes downward toward the center**, encouraging gravity-driven muck movement.
  - Is connected to **vacuum tubes** to remove mud efficiently.

- An **oppositely spinning ring** on the cutter head:
  - Functions as a **grinder**, reducing rock size and minimizing clogging risks.
  - Aims to increase throughput by producing finer particles suitable for vacuum or auger capture.

## Action Items
- [ ] CAD sketch of auger and domed chamber layout
- [ ] Simulate rock/mud separation using filter slope geometry
- [ ] Estimate vacuum pressure and auger speed requirements

## Next Meeting
**Date:** 6-4-25 
**Agenda:** Review CAD, finalize excavation subsystem interface with structural frame

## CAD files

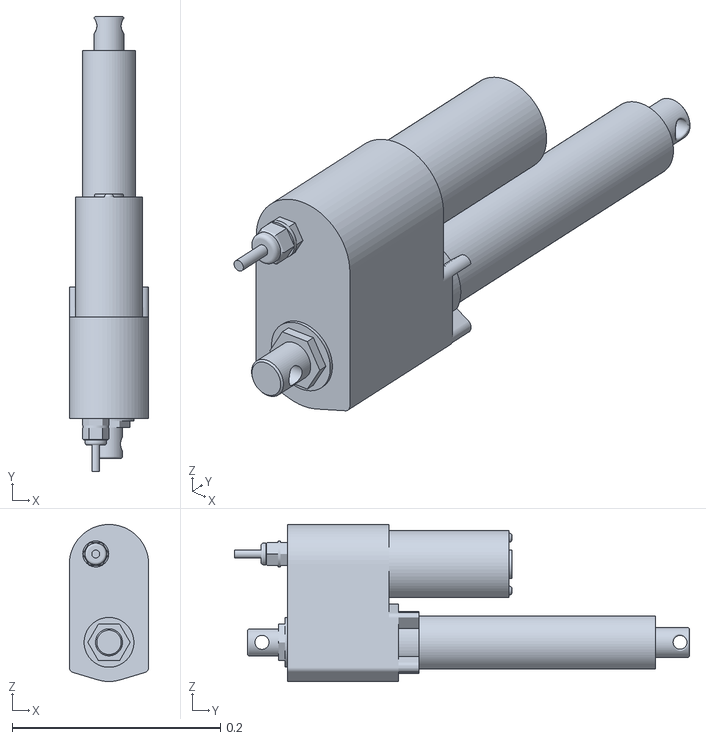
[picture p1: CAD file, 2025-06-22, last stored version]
design/CAD/PA-17 Linear Actuator.stl
0.0762 x 0.437 x 0.151

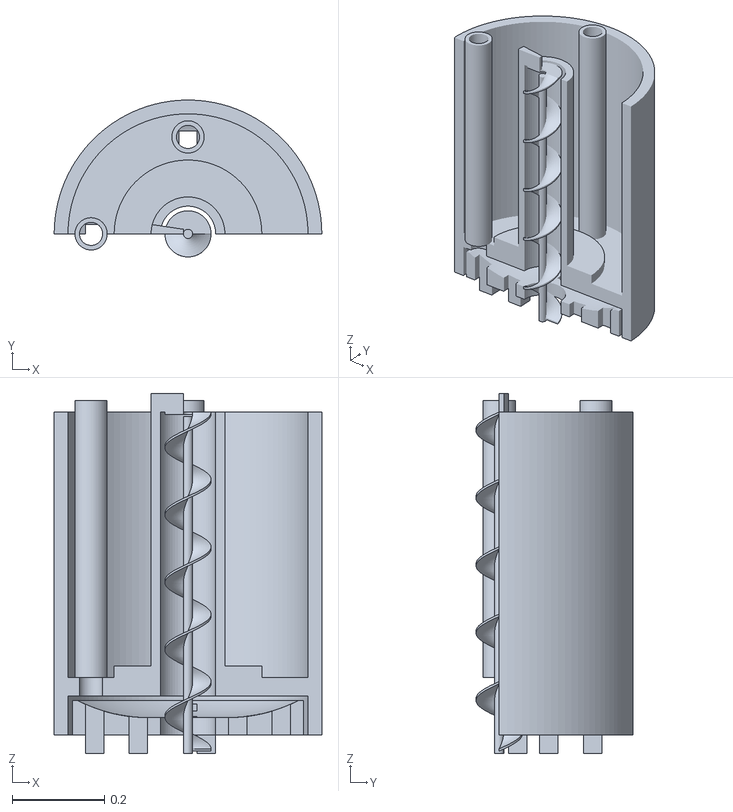
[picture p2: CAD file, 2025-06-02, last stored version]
media/TBM Mk1.stl
0.58 x 0.34 x 0.78

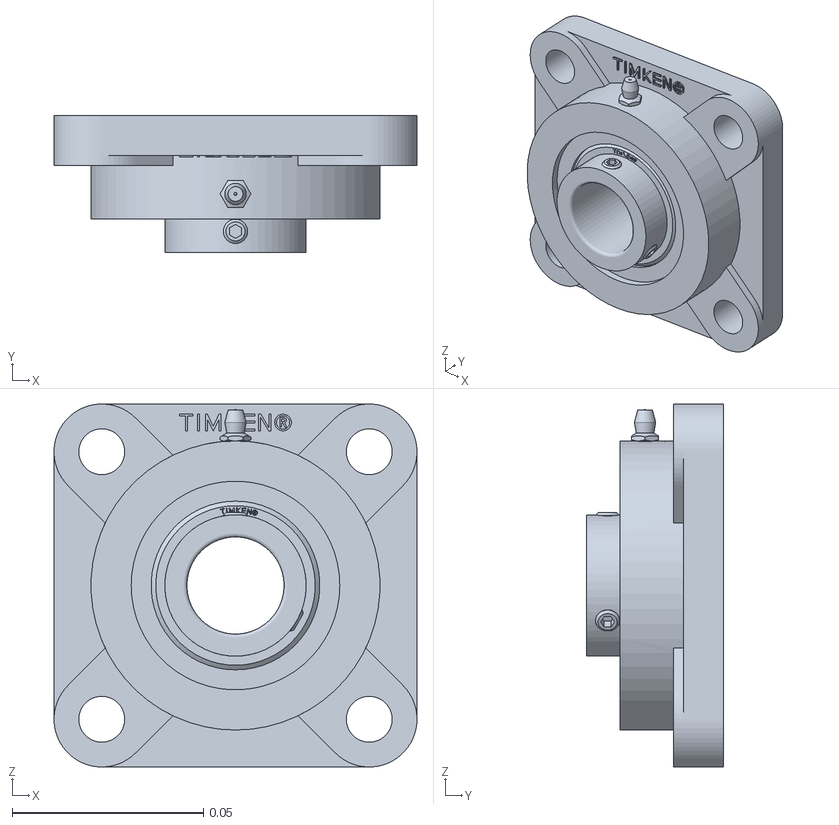
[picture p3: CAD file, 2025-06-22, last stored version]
design/CAD/UCF205-16 Flange Bearing.stl
0.095 x 0.0358 x 0.095

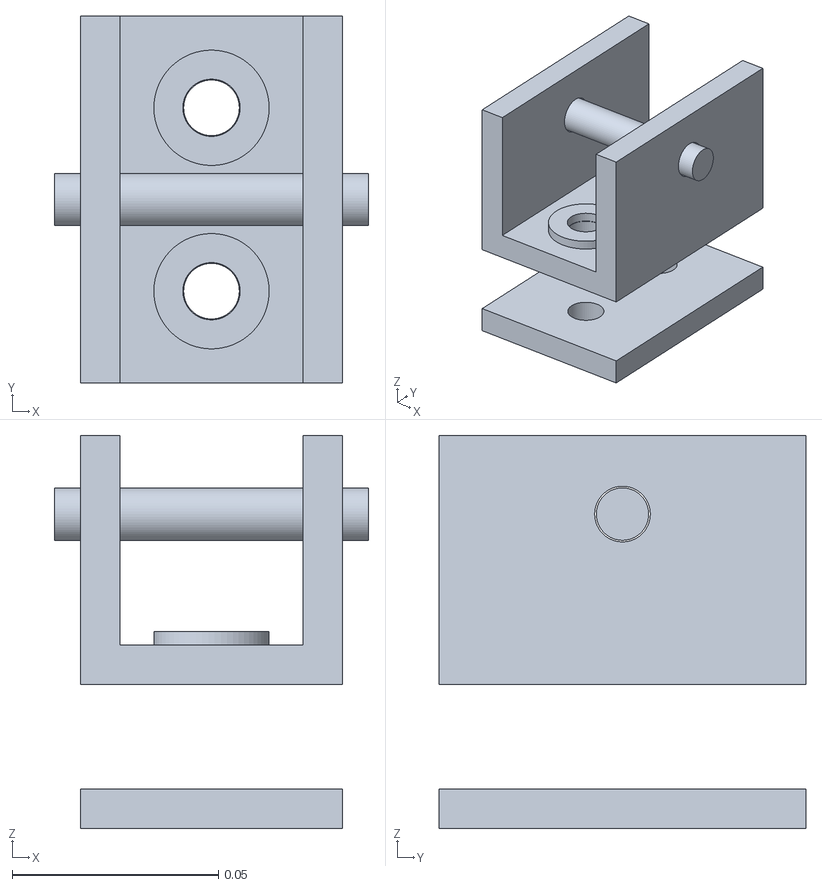
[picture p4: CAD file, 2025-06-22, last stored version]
design/CAD/Linear Actuator Bracket.stl
0.0762 x 0.0889 x 0.0952

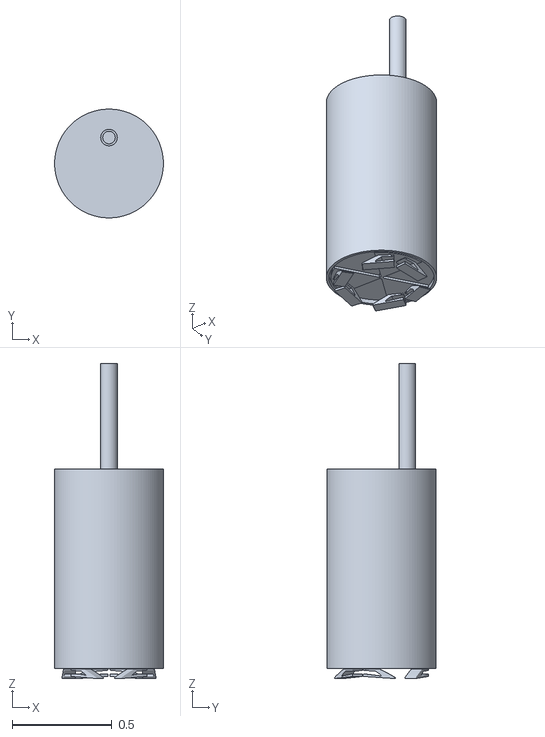
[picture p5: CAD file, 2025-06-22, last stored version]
design/CAD/TBM Mk4.stl
0.545 x 0.545 x 1.58

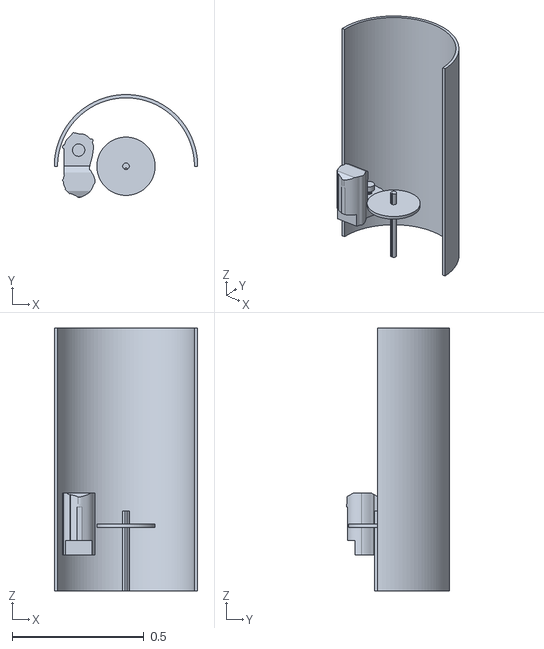
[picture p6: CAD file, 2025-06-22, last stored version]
design/CAD/TBM Mk5 (in progress).stl
0.545 x 0.391 x 1.00

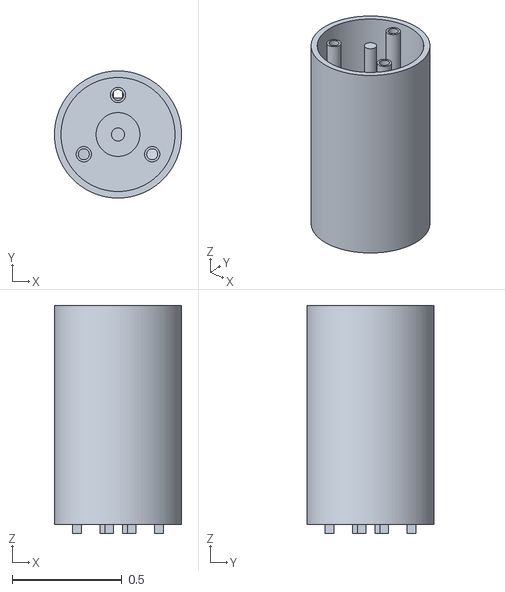
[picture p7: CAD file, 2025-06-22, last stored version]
design/CAD/TBM Mk3.stl
0.58 x 0.58 x 1.04

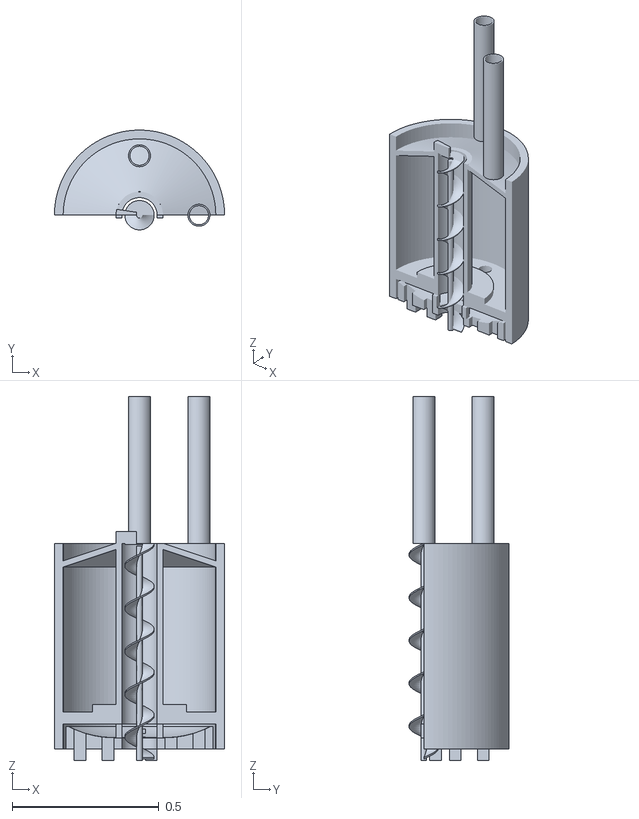
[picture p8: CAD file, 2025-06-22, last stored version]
design/CAD/TBM Mk2.stl
0.58 x 0.34 x 1.24

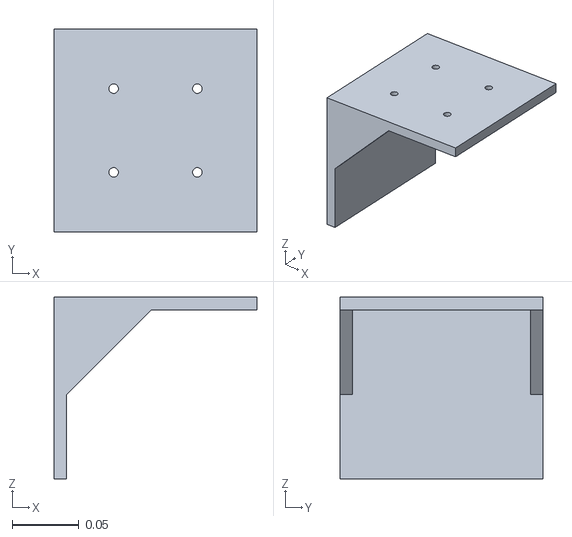
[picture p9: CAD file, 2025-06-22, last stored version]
design/CAD/Motor Bracket.stl
0.152 x 0.152 x 0.137

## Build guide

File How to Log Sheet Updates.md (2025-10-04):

# How to Log Sheet Updates

1. Open a Google Sheet
2. Extensions ➡️ Apps Script ➡️ Project Settings ➡️ Script Properties:

| Property | Value |
|---|---|
| GH_BRANCH | main |
| GH_LOG_PATH | logs/[INSERT SPREADSHEET NAME HERE]_changes.ndjson |
| GH_OWNER | maxweinstein77 |
| GH_REPO | UATXcavators |
| GH_TOKEN | [Max's UATXcavators-specific fine-grain PAT] |

3. Save Script Properties
4. Copy/paste the following code into Editor and hit save
5. Select createInstallableEditTrigger in the function dropdown menu and hit run
6. Review permissions ➡️ [your account] ➡️ Advanced ➡️ Go to [project name] (unsafe) ➡️ select all permissions and hit continue
7. All changes in *just that spreadsheet* will be posted to the file location specified in JSON format
8. Confirm with bottom-right corner pop-up in sheet: ✅ Logged edit: [col][row]

```
/*** UI helpers you already tested ***/
function test_commit() {
  // Runs the GitHub test so you can confirm everything without editing a cell
  testCommit_();
  SpreadsheetApp.getActive().toast('✅ Sent test line to GitHub');
}

function onOpen() {
  SpreadsheetApp.getUi()
    .createMenu('GitHub Logger')
    .addItem('Run test_commit', 'test_commit')
    .addToUi();
}

/*** EDIT LOGGER ***/
// NOTE: Simple triggers (onEdit) cannot call UrlFetchApp (GitHub). Make it a no-op to avoid errors/double-logs.
function onEdit(e) {
  // Intentionally empty. The installable trigger below (onEditHandler) does the real work.
}

/*** Installable edit handler (same logic as your original onEdit) ***/
function onEditHandler(e) {
  try {
    if (!e || !e.range || e.range.getNumRows() !== 1 || e.range.getNumColumns() !== 1) return;

    const cfg = getConfig_();
    if (!cfg.token || !cfg.owner || !cfg.repo) {
      console.error('Missing GitHub config in Script Properties');
      return;
    }

    // (Optional) limit to a specific tab or range:
    // if (e.range.getSheet().getName() !== 'Inputs') return;

    const sh   = e.range.getSheet();
    const row  = e.range.getRow();
    const col  = e.range.getColumn();
    const when = new Date().toISOString();

    const before = (typeof e.oldValue !== 'undefined') ? String(e.oldValue) : null;
    const after  = (typeof e.value     !== 'undefined') ? String(e.value)     : null;

    const record = {
      ts: when,
      sheet: sh.getName(),
      a1: e.range.getA1Notation(),
      row, col,
      old: before,
      new: after,
      user: (function(){ try { return Session.getActiveUser().getEmail() || null; } catch(_){ return null; } })()
    };

    appendLineToGithub_(cfg, JSON.stringify(record));
    // Optional UX ping so you know it fired
    SpreadsheetApp.getActive().toast('✅ Logged edit: ' + e.range.getA1Notation());
  } catch (err) {
    console.error('[onEditHandler] ' + err);
  }
}

/*** One-time creator for the installable trigger ***/
function createInstallableEditTrigger() {
  // Remove any existing duplicates (safe)
  ScriptApp.getProjectTriggers().forEach(t => {
    if (t.getHandlerFunction && t.getHandlerFunction() === 'onEditHandler') {
      ScriptApp.deleteTrigger(t);
    }
  });

  ScriptApp.newTrigger('onEditHandler')
    .forSpreadsheet(SpreadsheetApp.getActive())
    .onEdit()
    .create();

  SpreadsheetApp.getActive().toast('✅ Installable onEdit trigger created');
}

/*** Config + GitHub helpers ***/
function getConfig_() {
  const p = PropertiesService.getScriptProperties();
  return {
    owner:  p.getProperty('GH_OWNER'),
    repo:   p.getProperty('GH_REPO'),
    branch: p.getProperty('GH_BRANCH')   || 'main',
    path:   p.getProperty('GH_LOG_PATH') || 'logs/Sensors_Actuators_Controls_List_changes.ndjson',
    token:  (p.getProperty('GH_TOKEN') || '').trim()
  };
}

function appendLineToGithub_(cfg, line) {
  const {content, sha} = getGithubFile_(cfg, cfg.path);
  const newContent = (content ? content + '\n' : '') + line;
  const msgPreview = line.length > 72 ? (line.slice(0,72) + '…') : line;
  putGithubFile_(cfg, cfg.path, newContent, `Sheets change: ${msgPreview}`, sha);
}

function getGithubFile_(cfg, path) {
  const api = `https://api.github.com/repos/${encodeURIComponent(cfg.owner)}/${encodeURIComponent(cfg.repo)}/contents/${encodeURIComponent(path)}?ref=${encodeURIComponent(cfg.branch)}`;
  const headers = ghHeaders_(cfg.token);
  const resp = UrlFetchApp.fetch(api, {method: 'get', headers, muteHttpExceptions: true});
  const code = resp.getResponseCode();

  if (code === 200) {
    const data = JSON.parse(resp.getContentText());
    const decoded = Utilities.newBlob(Utilities.base64Decode(data.content)).getDataAsString();
    return { content: decoded, sha: data.sha };
  }
  if (code === 404) {
    return { content: '', sha: null };
  }
  throw new Error(`[getGithubFile_] HTTP ${code}: ${resp.getContentText()}`);
}

function putGithubFile_(cfg, path, textContent, message, sha) {
  const api = `https://api.github.com/repos/${encodeURIComponent(cfg.owner)}/${encodeURIComponent(cfg.repo)}/contents/${encodeURIComponent(path)}`;
  const headers = ghHeaders_(cfg.token);
  const body = {
    message,
    content: Utilities.base64Encode(textContent, Utilities.Charset.UTF_8),
    branch: cfg.branch
  };
  if (sha) body.sha = sha;

  const resp = UrlFetchApp.fetch(api, {
    method: 'put',
    headers,
    contentType: 'application/json',
    payload: JSON.stringify(body),
    muteHttpExceptions: true
  });
  const code = resp.getResponseCode();
  if (code >= 300) throw new Error(`[putGithubFile_] HTTP ${code}: ${resp.getContentText()}`);
}

function ghHeaders_(token) {
  return {
    Authorization: `Bearer ${token}`,            // fine-grained PAT → Bearer
    Accept: 'application/vnd.github+json',
    'X-GitHub-Api-Version': '2022-11-28',
    'User-Agent': 'google-apps-script'
  };
}

/*** Self-test that writes a line to GitHub ***/
function testCommit_() {
  const cfg = getConfig_();
  appendLineToGithub_(cfg, JSON.stringify({ts:new Date().toISOString(), test:true}));
  Logger.log('Test line pushed.');
}

function validateGithubAuth_() {
  const cfg = getConfig_();
  if (!cfg.token) throw new Error('No GH_TOKEN set.');
  const headers = ghHeaders_(cfg.token);

  let r = UrlFetchApp.fetch('https://api.github.com/user', {headers, muteHttpExceptions:true});
  Logger.log('GET /user -> ' + r.getResponseCode());              // expect 200

  const repoUrl = `https://api.github.com/repos/${encodeURIComponent(cfg.owner)}/${encodeURIComponent(cfg.repo)}`;
  r = UrlFetchApp.fetch(repoUrl, {headers, muteHttpExceptions:true});
  Logger.log('GET /repos/:owner/:repo -> ' + r.getResponseCode()); // expect 200
}

```

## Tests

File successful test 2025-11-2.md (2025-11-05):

# Test Setup

* Anti-torque control with a chopstick arm (2x4) where two protruding steel plates hugged the outer diameter of the PVC mucking tube and stopped it from twisting (with some tolerance)
* A linear actuator running on 240VAC to power the servo, + 24VDC from our RSP PSU to power the controller. Presses the jog button at 0.125 in/sec to press the TBM into the ground.
* First operator on HP laptop controlling the linear actuator in the wizard, manually jogging a 1-2 seconds at a time in either direction, then letting the cutterhead spin in the ground for ~10-30 seconds after each downward jog.
* Gantry lifted two cinder blocks high for clearance between the TBM and the ground. ~100lb sandbag counterweights on the corners.
* Motor inside the TBM running at different speed modes in both directions. Wiring for the motor was ferruled and extended, while the motor driver was taped to a gantry leg. Motor powered by the same PSU as the actuator controller (wires stacked on DC outputs).
* Driver, ESP32, and breadboard taped onto cardboard. The second operator is sitting a foot away from the ESP32 with a micro USB connection.
* Conditioning system including a peristaltic pump to dose dish soap and a diaphragm pump to send water supply down a single line. Then, a manifold splits the streams and rests on the surface. Diaphragm pump and peristaltic, both 12V, powered by a car battery.
* The third operator touches both pumps' negative terminals (black wires) to the negative terminal of the battery to complete the circuit (red + already connected) to spray soapy water from the manifold.
* Generator ran on propane.
* A wet/dry vacuum connected to the external PVC tube on the TBM, sucking up muck above the cutter head and dumping it into a Home Depot bucket.

# Observations
* Initial DC voltage link low errors on the linear actuator wizard. Simultaneous circuit-breaking on the 120VAC generator ports when two slots were used for the actuator's main power + controls. This was even after a new receptacle on the problematic one. This was solved by using 240VAC to power the actuator, which was in a different receptacle with more current. We suspect the current rating on the 120VAC outlet was insufficient to handle both actuator loads.
* There was backflow when continuously running the peristaltic dosing pump (soap) and the diaphragm pump (water supply). But, loading up the line with the peristaltic first, and then consecutively running the diaphragm pump did solve the backflow. 
* When jogging the linear actuator, in case of a motor stall, if reversing direction worked, it only worked the first time (i.e., when the motor operator hit 'R' on the keyboard once). But if >1 reversal happened and the motor was still stalled, reversing repeatedly afterwards did nothing. In that case, jogging the linear actuator to retract slightly allowed the cutter head to start spinning again. Then, we jogged back down to continue digging.
* Motor stalls occurred temporarily (1-2 seconds) if a rock was in the way or the cutter head caught on something. Stalls that necessitated motor reversals/jogs to break free happened when the cutter head wasn't allowed to cut the same spot for long enough ("idle time"). Stalling happened <10 seconds of cutter head idle time. Using the jog speed above, this implies that the TBM could sustain a max speed of .0125in/sec (a 1-second jog every 10 seconds) or 19mm/min.
* The vacuum successfully picked up the muck, even at a distance of about 1” from the muck level. The largest particle it picked up was .68in (from inside the disposal bucket). It clogged 2-3 times, and during clogs, flushing the tube with water and ensuring the intake was not immersed in water was sufficient to continue suction. Inside the disposal bucket, there was an 8-inch high material, three layers of material formed (@ 10in diameter, that is about 2.75gal). ~½ of the height was warm form, then the bottom part was noticeably cooler silt, with the density increasing as we went down. We confirmed this separation was due to settling. The inner diameter of the PVC tube is .75in, which means it fits a .68in particle. Because there was no curve in this smaller tube, by the time there was a curve, it was already in the larger 1.25-inch-diameter vacuum tube and had space to move.
* We dug a 5-inch deep, 9-inch diameter hole.
* The metal on the end of the chopstick arms began to bend since there was only one set of screws and it was on the opposite end, creating a torque arm/bending moment. Also, as the TBM lowered into the ground, the reaction arm on the top end of the PVC tube created a torque arm at the bottom, causing shakiness in the cutter head. This requires another reaction arm at the bottom. A good idea is to create a cutout of the machine with a wooden plate and then situate the cinders on top of it to stop it from twisting. The cutout part hugs the external PVC pipe.
* The soapy water successfully created a slurry and loosened the ground. 

# For the future
* Add sensors for current, RPM, and vibration, to automate and get feedback from the motor to respond with movements with the actuator when it stalls.
* Use a dye to detect backflow and valve to mitigate it.
* Add methods to control the pump flow/current.
* Alligator clips to safely connect wires to the battery.
* Switches to turn on and off the two pumps rather than repeatedly touching the wire.
* Automate the linear actuator control instead of manually jogging. Get data on current, stroke length, and advance speed that we can control for and experiment with.
* Create a better anti-torque control method by stabilizing the bottom of the TBM—and allowing for deeper digging. Make the metal pieces on the 2x4 more sturdy–scale them back and use the second set of screws, or buy longer, thicker, narrower pieces (~$4 at Ace).
* Test with professional conditioner and record data vs dry or soapy conditions.
* Test and compare different cutter head designs (e.g., with smaller bolts and/or gaps) and record max tunneling speeds.
* Use an emergency stop in the motor code so that it doesn’t loop through and delay when we need to immediately shut down, but instead bypasses control logic.
* Do a better spray paint job on the TBM. 
* Go DEEPER (up to the max stroke length)!

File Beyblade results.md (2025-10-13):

# 1. Finding the force specs for our rubber band

| Unstretched (cm) | Stretched (cm) |
| :--- | :--- |
| 18 | 87 |
| 15 | 65 |
| 12 | 52 |
| 9 | 45 |
| 6 | 28 |
| 3 | 15 |

In this experiment, we lifted a fixed weight of 5.2 N (a 500 mL plastic bottle), pinching a rubber band at the unstretched length, and then recording the stretched length at which the rubber band could lift the fixed weight (when the bottle overcame gravity).

$$
\begin{aligned}
F = EA \frac{\Delta L}{L_0}
\end{aligned}
$$

Here, $EA$ is a constant, and so force is proportional to the ratio between the change in length and the unstretched state. When there is less original length, there is more force since there is less slack and the band resists more. 

Strain $\sigma$ is another way to think of $\frac{\Delta L}{L_0}$, which is just a way to measure and an equalized version of the deformation (since it adjusts for original length). 

Stress is different--it is the force applied per area of material. A way to see a material's durability, for instance, is to measure its stress vs. strain. $E$ is how stiff the material is in N/m^2, which is the relationship between stress and strain, calculated as:

$$
\begin{aligned}
E = \frac{\text{stress}}{\text{strain}} = \text{stress} \times \frac{L_0}{\Delta L} \implies stress = E \times \frac{\Delta L}{L_0}
\end{aligned}
$$

To get back to force $F$, the stress times the area, since stress is a kind of pressure metric:

$$
\begin{aligned}
F = \text{stress} \times A = EA \frac{\Delta L}{L_0}
\end{aligned}
$$

From our experiment, $EA$ = 1.42 N, SD ≈ 0.12 N

# 2. Determining the relationship between rubber band force and cutter head turn count

We measured wetted dirt at .558lb/cup, which is 1070kg/m^3. Then, we measured out an unstretched (nearly taut) rubber band from the cutter head center to the edge on both sides, then wrapped the rubber band around a central spindle on the cutter head, and released as the cutter head span due to the rubber band contraction. Finally, we recorded the number of revolutions of the cutter head.

We did this for 1 - 4 wraps, with a band distance of 15cm and then 32cm on each side.

We can define wrap count in terms of $\Delta L$ of the rubber band by using the circumference of the spindle, about 4cm. 

Not including the zeros, here are the statistical averages and force computations (given $EA$ = 1.42N) for $L_0$ = 15cm, where $R$ is revolutions (for computational simplicity, we assume only a one-rubber-band-spin for now, but later we will double forces since the setup uses two, symmetric rubber bands that pull in the same rotational sense):

| $\Delta L$  (cm) | $R$ | Force (N) |
| :--- | :--- | :--- |
| 4 | didn't turn | 0.38 |
| 8 | $\mu = .775$, SD = .035 | 0.76 |
| 12 | $\mu = 1.25$, SD = .12 | 1.14 |
| 16 | $\mu = 2.22$, SD = .2 | 1.52 |

For $L_0$ = 32cm:

| $\Delta L$ (cm) | $R$ | Force (N) |
| :--- | :--- | :--- |
| 4  | didn't turn | 0.18 |
| 6  | $\mu = .625$, SD = 0 | 0.27 |
| 8  | 1 | 0.36 |
| 10 | $\mu = 1$, SD = .35 | 0.44 |
| 12 | 1.65 | 0.53 |
| 14 | 2 | 0.62 |
| 16 | 2.75 | 0.71 |

It's reassuring to see that we get around half the force values when our band length doubles.

To determine the relationship between force and revolutions, we must therefore adjust for $L_0$ (cm). Suppose $F^* = FL_0$. Then, our empirical pattern is:

| $F^*$ (N·cm) | $R$ | $k_i$ (rev/N·cm) |
| :---: | :---: | :---: |
| 8.6  | 0.625 | 0.073 |
| 11.4 | 0.775 | 0.068 |
| 11.5 | 1.000 | 0.087 |
| 14.1 | 1.000 | 0.071 |
| 17.0 | 1.650 | 0.097 |
| 17.1 | 1.250 | 0.073 |
| 19.8 | 2.000 | 0.101 |
| 22.7 | 2.750 | 0.121 |
| 22.8 | 2.220 | 0.097 |

Taking the statistics of $k$, we get $\mu = 0.0876$, SD = .017. That describes the linear assumption: $kF^* = R$.

Using Google Sheets to find the line of best fit, we obtain the equation: 0.671 + -0.0522x + 5.82E-03x^2. This has an RMSE of .18 (better than our linear version). The small coefficient on the squared term suggests it's probably linear. What may be non-linear, and something that has been cleaned from the data thus far, is the number of revolutions when accounting for zero turns. This happens when we let go of the rubber bands, and the cutter head doesn't move.

Here is a table counting the percentage of "zeroes" that happened (for $L_0$ = 15cm, 5 trials each):

| Wrap count | Zeroes % |
| :--- | :--- |
| 1 | 100 |
| 2 | 80 |
| 3 | 20 |
| 4 | 0 |

# 3. Computing breakaway torque

From this data, we learn there is a threshold of force that is required to "kickstart" the cutter head--this is likely why teams who get stuck switch the direction of their cutter head. The impulse creates some inertia that makes the newly moving cutter head easier to continue moving, rather than starting at rest. This impulse may also be part of what overcomes the shearing component of the ground.

We also haven't mentioned that the rubber band force will decrease over time as the cutter head turns and adds slack to it. But we can still use the instantaneous force $F$, which happens at the moment of release, to inform our understanding of overcoming ground pressure components.

Returning to this *threshold force*, we can estimate it as the midpoint between the force at zero turns and the force at the first nonzero turn. That can get us a best guess at the *breakaway torque* $\tau$ at radius = 2cm. So we have:

| $L_0$ (cm) | “didn’t turn” $F$ (N) | First turn $F$ (N) | Estimated $F_{\text{turn}}$ (N) | Breakaway Torque $\tau = rF_{\text{turn}}$ (N·m) |
| :--- | :--- | :--- | :--- | :--- |
| 15 | 0.38 | 0.76 | ≈ 0.55 | **0.011** |
| 32 | 0.18 | 0.27 | ≈ 0.23 | **0.0046** |

So, $\tau = .008 \pm .003\text{Nm}$

Now, we can do the same experiment for another cutter head type and compare the breakaway torque to determine the cutter head efficiency.

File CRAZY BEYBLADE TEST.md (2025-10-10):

# This is crazy

In the Cutter Head test, henceforth known as "CRAZY BEYBLADE TEST" on  10/11/25, we are going to measure a proxy for *p*, i.e., how many revolutions it takes to plane/clear a surface under (near) zero thrust. That will tell us something about the cutting geometry, which would be obscured by the advance rate of our actuator/jacks in future tests. In other words, we are doing *p* for broke people. 

Ingredients:

1. A container that has a diameter of greater than 4".
2. A luggage scale with at least .2 pounds precision.
3. Four, 3D-printed cutter heads: at least the current one, sharp cut, bigger center scraper, and taller scrapers
4. 4 "spools" epoxied on each cutter head
5. A bunch of rubber bands, two epoxied on each spool on opposing sides
6. A gallon of water
7. Measuring cups
8. Ruler
9. The maximum wrap count *w* of a rubber around the spool.
10. A fixed weight.

Steps:
1. Print the 4 cutter heads and epoxy a spool onto each one.
2. Cut two rubber bands and epoxy an end of each 180 degrees apart on the spool. Do this for all spools/cutter heads => Beyblades. Record 
3. Go to our Brackenridge lot with the equipment and collect a controlled volume of dirt (~1-2 cups).
5. Place the dirt in the container and add a controlled amount of water (e.g., 2 tablespoons).
6. Weigh the dirt and record the density. The volume, weight, and density must be held constant for all tests (so add and subtract as necessary).
7. Take a Beyblade, clean off the dirt, and center it on the container's patted dirt.
8. Mark a fixed distance away from the Beyblade to fix each rubber band end, and test a spot that slows down the velocity (allowing for more precise measurements and recordings). If you have time, try a new distance to test the cutter head types at a different angular velocity.
9. Set up a slo-mo camera in view of the cutters hitting the ground.
10. While holding the rubber bands, crank the Beyblade an incremental number of revolutions, starting at 1.
11. Place the fixed weight on the Beyblade for a fixed (TBD) number of seconds so that it presses into the dirt. Make sure there is no weight during the test.
12. Then, hit record on the slo-mo and LET IT RIP.
13. Let the Beyblade slow to a stop, then pick it up and snag a picture of the hole it made in the dirt.
14. Take a measurement using the ruler of the deepest and shallowest crevice. Estimate the average crevice depth with a margin of error?
15. Do this 5 times for each revolution number, ending *w*.
16. Then, increase the revolution amount, and loop this over again.
17. Finally, loop this for each cutter head type.

Your data should be an array of shape(5, 4, *w*). 5 repeats for each of the 4 cutter heads' *w* trials.

Post processing:
* Determine how much was excavated by comparing photos.
* Compare the crevices' depths and averages across the cutter heads.

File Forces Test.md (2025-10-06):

Best option $100: these top two links should be good just look through them and make sure there good.

Motor $40
https://www.amazon.com/Torque-Stepper-Motor-425oz-Router/dp/B00PNEPW4C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

stepper 20:1 $60
https://www.amazon.com/STEPPERONLINE-Planetary-Gearbox-Gear-Ratio/dp/B0BPGNXJTJ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

Here is a comprehensive chart for your **NEMA 23 stepper motor with MGL 20:1 planetary gearbox**, including motor max torque, gearbox max torque, output RPM, and torque under axial loads for a 2-inch radius TBM cutter head:

| Axial Load (lb) | Axial Force (N) | Required Torque (Nm) | Motor Torque (Nm) | Gearbox Output Torque (Nm) | Max Motor Torque (Nm) | Max Gearbox Torque (Nm) | Max Output RPM |
| --- | --- | --- | --- | --- | --- | --- | --- |
| 0 | 0 | 0 | 3.0 | 60.0 | 3.0 | 60.0 | 250 |
| 50 | 222.4 | 11.3 | 0.565 | 11.3 | 3.0 | 60.0 | 203 |
| 90 | 400.3 | 20.3 | 1.015 | 20.3 | 3.0 | 60.0 | 165 |
| 130 | 578.3 | 29.4 | 1.47 | 29.4 | 3.0 | 60.0 | 128 |

**Notes:**

* **Motor Torque (Nm)** is the torque required from the motor to achieve the output torque, accounting for the 20:1 gearbox.
* **Gearbox Output Torque (Nm)** is motor torque multiplied by gear ratio.
* **Max Motor Torque (3.0 Nm)** is the holding torque at 0 RPM.
* **Max Gearbox Torque (60 Nm)** is the gearbox-amplified holding torque.
* **Max Output RPM** is calculated as output speed after the 20:1 gearbox based on motor torque-speed curve.

 other option 1: 
4:1 Stepperonline $72- cannot withstand max axiel force
 https://www.amazon.com/STEPPERONLINE-Planetary-Gearbox-Stepper-Router/dp/B00WAUZ1WU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

| Load | Torque at drum | Motor torque required | Motor rated torque | Max output RPM |
| --- | --- | --- | --- | --- |
| 50 lb  | 11.3 Nm | 2.96 Nm | 4.78 Nm | 165 RPM |
| 90 lb  | 19.6 Nm | 5.13 Nm | 4.78 Nm | 82 RPM |
| 130 lb | 29.4 Nm | 7.69 Nm | 4.78 Nm | 41 RPM |

other option 2:
47;1 Stepperonline $73-cannot max Rpm too slow
https://www.amazon.com/47-Planetary-Gearbox-Stepper-Router/dp/B00WAV322U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

| Torque at drum (Nm) | Motor torque (Nm) | % Rated Motor Torque | Safe Step Frequency (Hz) | Output RPM |
| --- | --- | --- | --- | --- |
| 11.3 | 0.33 | 28 % | 10,000 | 1.39 |
| 19.6 | 0.57 | 48 % | 5,000 | 0.70 |
| 29.4 | 0.86 | 73 % | 2,500 | 0.35 |
| 40 (rated max) | 1.18 | 100 % | 1,000 | 0.14 |
| 60 (momentary) | 1.77 | 150 % | 500 | 0.07 |

other Option 3 and 4: combination $93: incapable of handling max Axial load

motor $40
https://www.amazon.com/Torque-Stepper-Motor-425oz-Router/dp/B00PNEPW4C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

Stepper 10:1 $53
https://www.amazon.com/STEPPERONLINE-MGL-Gear-Ratio-Planetary/dp/B0DY13MZSV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

| Axial Load (lb) | Torque at Drum (Nm) | Motor Torque Required (Nm) | Motor Rated Torque (Nm) | Gearbox Max Torque (Nm) | Output RPM |
| --- | --- | --- | --- | --- | --- |
| 0 | 0.0 | 0.0 | 3.0 | 25 | 50 |
| 50 | 11.3 | 1.41 | 3.0 | 25 | 50 |
| 90 | 20.3 | 2.53 | 3.0 | 25 | 50 |
| 130 | 29.4 | 3.67 | 3.0 | 25 | 41 |

Stepper 50:1 $60

https://www.amazon.com/STEPPERONLINE-Planetary-Gearbox-Gear-Ratio/dp/B097SD1ZLQ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

| Axial Force (lb) | Axial Force (N) | Torque at Drum (Nm) | Motor Torque Required (Nm) | Motor RPM | Output RPM | Max Motor Torque (Nm) | Max Gearbox Torque (Nm) |
| --- | --- | --- | --- | --- | --- | --- | --- |
| 50 | 222 | 11.3 | 0.71 | 300 | 15 | 3 | 25 |
| 50 | 222 | 11.3 | 0.71 | 400 | 20 | 3 | 25 |
| 50 | 222 | 11.3 | 0.71 | 500 | 25 | 3 | 25 |
| 50 | 222 | 11.3 | 0.71 | 600 | 30 | 3 | 25 |
| 90 | 400 | 20.3 | 1.27 | 300 | 15 | 3 | 25 |
| 90 | 400 | 20.3 | 1.27 | 400 | 20 | 3 | 25 |
| 90 | 400 | 20.3 | 1.27 | 500 | 25 | 3 | 25 |
| 90 | 400 | 20.3 | 1.27 | 600 | 30 | 3 | 25 |
| 130 | 578 | 29.4 | 1.84 | 300 | 15 | 3 | 25 |
| 130 | 578 | 29.4 | 1.84 | 400 | 20 | 3 | 25 |
| 130 | 578 | 29.4 | 1.84 | 500 | 25 | 3 | 25 |
| 130 | 578 | 29.4 | 1.84 | 600 | 30 | 3 | 25 |

stepper

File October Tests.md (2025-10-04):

# October Tests
The purpose of this doc is to explain what October's tests will look like.

## Test Schedule

October's test objectives are to determine:
1. The best cutter head design
2. How to operate the conditioning subsystem
3. Expected forces for structural, propulsion, and cutter head systems

This fits into our broader goals of:
* Submitting the November Design Briefing (NDB) by November 4th (in 1 month)
* Preparing for our sequentially built and tested, full-sized TBM

### Future Tests
| Deadline | Test |
|---|---|
| Monday, October 13 | Cutter Head Test |
| Monday, October 20 | Forces Test|
| Monday, October 27 | Conditioning Test |

> 🚨 As we source parts, always weigh the tradeoffs of sourcing in-house or off-the-shelf. 

### Cutter Head Test

Let *p* be how much ground in mm the TBM eats per revolution of the cutter head, and *RPM* be the number of cutter head revolutions every minute. Then, 

$$
\begin{aligned}
\text{TBM speed (mm/min)} = p \ \text{(mm/rev)} \times \textbf{RPM}
\end{aligned}
$$

We want to increase speed. So, **Cutter Head Test**'s goal is to find the cutter head design that maximizes *p*. 
Subgoals:
* Find a low-cost way to measure *p* accurately: how do we measure how much stuff is torn up by the cutter head?
* CAD cutter head designs and 3D-print them
* Set up controlled variables, including thrust, RPM, and ground conditions

**Cutter Head Test**'s item dependencies:
* 3D-printed cutter head
* TBD materials for the experiment

### Forces Test

We need to know how to push the machine into the ground to 1) overcome friction and 2) control reaction torque.
Because of that pesky opposite reaction law, we also need a launch structure to handle the force coming off the ground.

**Forces Test** will entail a small TBM prototype:
* Torque mechanism (Jema motor delivery 10/16)
* Thrust mechanism (Valin linear actuator in dorm or gravity)
* Structure (3D-printed guide ring, launch structure, TBM body, and cutter head)
* ESP32/FPGA/stock controls, current & voltage & load cell sensors

This small-scale test is for gauging our force expectations for the real version and submitting them with the NDB, as well as finding designs that minimize specific energy (*SE*).
Objectives include:
* Measure the ground pressure for various ground conditions--very useful in physics calculations
* Measure loads on all structures
* Measure reaction torque at different ramp-ups, push speeds, and mediums
* Measure *SE* across various experimental scenarios 
* Iterate all structural designs (guide ring, et.al.)
* Do a friction analysis both axially and with torque (NDB)

### Conditioning Test

All future subsystem tests will feature the conditioning subsystem to create real cutting conditions. So, we need to determine the following:
* Injection ratio (how much conditioner vs. dirt)
* How to transport conditioner from the mixer tank (start) ➡️ tunnel face (finish)
* How to mix the conditioner and water
* How to operate the pump (including software, mechanical, and electrical)
* Whether we need a pump with different specs
* Whether ultrasound emitters are a good idea
* Which spray nozzle design to use

***Every test needs an optimization goal.*** For **Cutter Head Test**, that was maximizing *p*. For **Conditioning Test**, we are reducing $\tau$ (tau) and maximizing *p* simultaneously. 
Doesn't optimizing two things at once cause mediocre returns for both?
In this case, they behave hand-in-hand:
* $\tau$ is the torque needed to dig, which decreases when we condition (or loosen) sticky or hard ground. 
* Removing blockages on the cutter head's scrapers with conditioner makes them cut more effectively. That increases *p*.

**Conditioning Test**'s item dependencies:
* Pump: Pentair Shurflo #5059-1310-D011 (in our dorm)
* 1/2" tubing (dependent on 10/15-10/18 est. delivery from MSC)
* Solenoid valves (Amazon B09W9W5LF8)
* Pump current sensor (INA260)
* TBD controls/electronics
* TBD pump pressure sensor
* TBD other sensors (e.g. vibration/temp) and valves (e.g. clean)
* TBD any other parts for NABC compliance

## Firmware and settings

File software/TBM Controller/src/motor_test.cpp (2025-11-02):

#include <Arduino.h>

// Pin assignments
const int PUL_PIN = 18;
const int DIR_PIN = 19;
const int ENA_PIN = 21;  // ENA− connected here, ENA+ tied to +5V

// Motor & microstep specs
const int stepsPerRev = 1600;  // 200 full steps/rev * 8 microsteps/step

// Timing constants (µs)
const unsigned int SETUP_US = 100;     // DIR must settle before PUL rising edge
unsigned int PULSE_LEN_US = 250;   // keep PUL high for ≥ 2.5 µs

// Length of loop.
unsigned int LOOP_LEN = 3000; // Loop iterates every 3000 microseconds

bool isOn = false;
bool isReversed = false;

// Current rotator task.
int fullTaskLength = 0;
int remainingTaskLength = 0;
unsigned int taskTimeUS = 0;

void pulse(int length) {
    length /= 2;
    // Generate pulses to rotate motor
    digitalWrite(PUL_PIN, HIGH);
    delayMicroseconds(length);  // Adjust for speed
    digitalWrite(PUL_PIN, LOW);
    delayMicroseconds(length);
}

// Unneeded for now
/* 
int getSubtaskLength() {
    if ( remainingTaskLength == 0 ) return 0;
    int maxSubtaskLen = ceil(fullTaskLength * LOOP_LEN / taskTimeUS); 
    return (maxSubtaskLen >= remainingTaskLength) ? maxSubtaskLen : remainingTaskLength;
}
*/

void safeWritePin(int pin, int state) {
    digitalWrite(pin, state);
    delayMicroseconds(SETUP_US);
}

void setup() {
    Serial.begin(115200);
    delay(1000);
    Serial.println("Motor test with ENA control");

    pinMode(PUL_PIN, OUTPUT);
    pinMode(DIR_PIN, OUTPUT);
    pinMode(ENA_PIN, OUTPUT);

    // Idle states
    digitalWrite(PUL_PIN, LOW);
    digitalWrite(DIR_PIN, LOW);
    // Set ENA to disabled (high)
    digitalWrite(ENA_PIN, HIGH);
}

void loop() {
    // Whenever a character is typed, runs loop body
    if (Serial.available()) {
        String keyword = Serial.readString();
        switch (tolower(keyword.charAt(0))) {
            case 's':
                isOn = !isOn;
                safeWritePin(ENA_PIN, isOn);
                break;
            case 'r':
                isReversed = !isReversed;
                safeWritePin(DIR_PIN, isReversed);
                break;
            case '-':
            case '_':
                if (PULSE_LEN_US < 1000000)
                    PULSE_LEN_US *= 2;
                break;
            case '+':
            case '=':
                if (PULSE_LEN_US > 62)
                    PULSE_LEN_US /= 2;
                break;
            case 'p':
                Serial.printf("on: %d\n reversed: %d\n pulse length: %d us\n\n", isOn, isReversed, PULSE_LEN_US);
                break;
        }
    }

    if (isOn) {
        pulse(PULSE_LEN_US);
    }
}

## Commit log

2025-06-02 TBM CAD design
    [TBM Mk1.stl]
2025-06-02 TBM CAD
    [TBM Mk1.stl]
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2025-06-20 Create Rough PID Draft.md
2025-06-20 Update Rough PID Draft.md
2025-06-20 Update and rename budget_breakdown.xlsx to budget_breakdown.md
    [budget_breakdown.xlsx]
2025-06-22 Create UATX TBM Bracket Sandwich.md
2025-06-22 Update UATX TBM Bracket Sandwich.md
2025-09-29 removed dumb stuff
    removed
    [Final_Sourcing_BOM_with_Quantities.csv, Linear Actuator Bracket.stl, Motor Bracket.stl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]
2025-10-04 Sheets change: {"ts":"2025-10-04T20:17:21.412Z","sheet":"Sensors + Actuators + Controls…
2025-10-04 Sheets change: {"ts":"2025-10-04T20:17:43.140Z","sheet":"Sensors + Actuators + Controls…
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2025-10-04 Sheets change: {"ts":"2025-10-04T20:26:27.367Z","sheet":"Cost Breakdown II","a1":"J10",…
2025-10-04 Sheets change: {"ts":"2025-10-04T20:26:52.387Z","sheet":"Cost Breakdown II","a1":"J10",…
2025-10-04 Create Subsystem Ground Rules.md
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2025-10-04 Sheets change: {"ts":"2025-10-04T22:43:20.800Z","sheet":"Sensors + Actuators + Controls…
2025-10-04 Sheets change: {"ts":"2025-10-04T22:44:38.724Z","sheet":"Cutter Head","a1":"C7","row":7…
2025-10-04 Sheets change: {"ts":"2025-10-04T22:44:39.472Z","sheet":"Cutter Head","a1":"A2","row":2…
2025-10-05 Sheets change: {"ts":"2025-10-05T17:37:31.493Z","sheet":"Cutter Head","a1":"D17","row":…
2025-10-05 Sheets change: {"ts":"2025-10-05T17:37:52.065Z","sheet":"Cutter Head","a1":"D8","row":8…
2025-10-05 Sheets change: {"ts":"2025-10-05T17:38:27.871Z","sheet":"Cutter Head","a1":"D9","row":9…
2025-10-05 Sheets change: {"ts":"2025-10-05T17:50:20.186Z","sheet":"Cutter Head","a1":"D9","row":9…
2025-10-05 Sheets change: {"ts":"2025-10-05T18:10:01.166Z","sheet":"Cutter Head","a1":"D9","row":9…
2025-10-05 Sheets change: {"ts":"2025-10-05T19:12:44.362Z","sheet":"Cost Breakdown II","a1":"F12",…
2025-10-05 Sheets change: {"ts":"2025-10-05T19:49:25.392Z","sheet":"Sensors + Actuators + Controls…
2025-10-05 Sheets change: {"ts":"2025-10-05T19:49:27.376Z","sheet":"Sensors + Actuators + Controls…
2025-10-05 Sheets change: {"ts":"2025-10-05T19:49:42.152Z","sheet":"Sensors + Actuators + Controls…
2025-10-05 Sheets change: {"ts":"2025-10-05T19:49:46.888Z","sheet":"Sensors + Actuators + Controls…
2025-10-05 Sheets change: {"ts":"2025-10-05T20:38:48.415Z","sheet":"Cost Breakdown II","a1":"H2","…
2025-10-05 Sheets change: {"ts":"2025-10-05T20:39:36.453Z","sheet":"Cost Breakdown II","a1":"H3","…
2025-10-05 Sheets change: {"ts":"2025-10-05T20:39:47.147Z","sheet":"Cost Breakdown II","a1":"H3","…
2025-10-05 Sheets change: {"ts":"2025-10-05T20:40:02.227Z","sheet":"Cost Breakdown II","a1":"H3","…
2025-10-05 Sheets change: {"ts":"2025-10-05T20:40:17.389Z","sheet":"Cost Breakdown II","a1":"H4","…
2025-10-05 Sheets change: {"ts":"2025-10-05T20:40:43.788Z","sheet":"Cost Breakdown II","a1":"H15",…
2025-10-05 Sheets change: {"ts":"2025-10-05T20:40:56.906Z","sheet":"Cost Breakdown II","a1":"G15",…
2025-10-05 Sheets change: {"ts":"2025-10-05T20:41:05.162Z","sheet":"Cost Breakdown II","a1":"H15",…
2025-10-05 Sheets change: {"ts":"2025-10-05T20:41:10.482Z","sheet":"Cost Breakdown II","a1":"H15",…
2025-10-05 Sheets change: {"ts":"2025-10-05T20:41:25.352Z","sheet":"Cost Breakdown II","a1":"H49",…
2025-10-05 Sheets change: {"ts":"2025-10-05T20:41:27.918Z","sheet":"Cost Breakdown II","a1":"H54",…
2025-10-05 Sheets change: {"ts":"2025-10-05T20:41:30.970Z","sheet":"Cost Breakdown II","a1":"H55",…
2025-10-05 Sheets change: {"ts":"2025-10-05T20:41:33.012Z","sheet":"Cost Breakdown II","a1":"H57",…
2025-10-05 Sheets change: {"ts":"2025-10-05T20:41:34.902Z","sheet":"Cost Breakdown II","a1":"H58",…
2025-10-05 Sheets change: {"ts":"2025-10-05T20:41:37.282Z","sheet":"Cost Breakdown II","a1":"H59",…
2025-10-05 Sheets change: {"ts":"2025-10-05T20:41:41.267Z","sheet":"Cost Breakdown II","a1":"H60",…
2025-10-05 Sheets change: {"ts":"2025-10-05T20:41:43.958Z","sheet":"Cost Breakdown II","a1":"H61",…
2025-10-05 Sheets change: {"ts":"2025-10-05T20:41:50.996Z","sheet":"Cost Breakdown II","a1":"H64",…
2025-10-05 Sheets change: {"ts":"2025-10-05T20:41:55.409Z","sheet":"Cost Breakdown II","a1":"I65",…
2025-10-05 Sheets change: {"ts":"2025-10-05T20:41:57.387Z","sheet":"Cost Breakdown II","a1":"I65",…
2025-10-05 Sheets change: {"ts":"2025-10-05T20:42:06.709Z","sheet":"Cost Breakdown II","a1":"H71",…
2025-10-05 Sheets change: {"ts":"2025-10-05T20:42:16.037Z","sheet":"Cost Breakdown II","a1":"H74",…
2025-10-05 Sheets change: {"ts":"2025-10-05T20:42:17.791Z","sheet":"Cost Breakdown II","a1":"H75",…
2025-10-05 Sheets change: {"ts":"2025-10-05T20:42:20.682Z","sheet":"Cost Breakdown II","a1":"H76",…
2025-10-05 Sheets change: {"ts":"2025-10-05T20:42:21.243Z","sheet":"Cost Breakdown II","a1":"H65",…
2025-10-05 Sheets change: {"ts":"2025-10-05T20:42:24.656Z","sheet":"Cost Breakdown II","a1":"H80",…
2025-10-05 Sheets change: {"ts":"2025-10-05T20:42:44.164Z","sheet":"Cost Breakdown II","a1":"H3","…
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2025-10-17 Motor Controls File + Updated USB Serial #
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
